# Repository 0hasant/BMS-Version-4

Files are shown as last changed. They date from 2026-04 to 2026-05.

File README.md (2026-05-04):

# Solar Team Solaris BMS Version 4

## To Do List

### Hardware Changes

1. Make the KiCad schematic more readable and understandable. Separate all ICs to their own sheets. Use hierarchical sheets. This applies to the whole project.
2. Fix the reset button issue. The RST pin is pulled low and is connected to ground through a pull-down resistor. Make the BQ76952 reset with software. // 02.05.2026 - Done by Hasan Turan.  - Hardware reset used.
3. Implement the sleep mode feature.
4. Connect the PACK pin to the positive terminal of the battery pack. //Done by Hasan Turan
5. Fix the VC0 and VC1 connections. // Done by Hasan Turan.
6. Add temperature reading to the BMS.
7. Fix the 5V regulator circuit. The cell connection can be reduced to 13 cells.
8. Revise the R32 and GND connection.// 02.05.2026 - Done by Hasan Turan.
9. Make the component naming system consistent.
10. Add an external balancing system.
11. Make the net name conventions consistent.

### Software Changes

1. Implement the voltage reading algorithm.// been doing by Hasan Turan.
2. Implement the current reading algorithm.// been doing by Hasan Turan.
3. Make a dedicated library for the BQ76952.// been doing by Hasan Turan.

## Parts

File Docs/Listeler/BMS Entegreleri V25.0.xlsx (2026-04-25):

Ürün Adı(Digi Key) | Şirket(Data Sheet) | Desteklenen Hücre Sayısı | Soc Desteği | Cloumb Counter | İnternal Regulator | Hücre Okuma Hassasiyeti | Diğer Özelikler | Fiyat | Fiyat Değişimi
MP2791DFP-0002-T (https://www.digikey.com/en/products/detail/monolithic-power-systems-inc/MP2787DFP-0000-T/22589390) | Monolithic Power Systems Inc. (https://www.monolithicpower.com/en/documentview/productdocument/index/version/2/document_type/Datasheet/lang/en/sku/MP2787DFP/document_id/9996/) | 7-16 | With MPF42790(no stock) | Error <±0.5% | 3.3V and 5V LDOs | Error <5mV (at 25°) | Hardware can be adjsut for OV-OC Protec. | $3.92 | $10.39
BQ76952PFBR (https://www.digikey.com/en/products/detail/texas-instruments/BQ76952PFBR/13427864) | Texas Instruments (https://www.ti.com/lit/ds/symlink/bq76952.pdf) | 3-16 | No | error < 1 µV (typical) | 3.3V and 5V | Error< 10 mV (typical) | Hardware can be adjsut for OV-OC Protec. | $4.66 | $9.65
TLE9012DQUXUMA1 (https://www.digikey.com/en/products/detail/infineon-technologies/TLE9012DQUXUMA1/15998980) | Infineon Technologies (https://www.infineon.com/assets/row/public/documents/10/49/infineon-tle9012dqu-datasheet-en.pdf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) | 1-12 | No | No | 3.3V | ±0.2 mV | Hardware can be adjsut for OV-OC Protec. | $7.15 | $7.16
ADES1754GCB/V+ (https://www.digikey.com/en/products/detail/analog-devices-inc-maxim-integrated/ADES1754GCB-V/22156883) | Analog Devices Inc./Maxim Integrated (https://www.analog.com/media/en/technical-documentation/data-sheets/ades1754-ades155-ades156.pdf) | 14 | No | No | 3.3V an 1.8V | Error <2.2mV | Battery-Management UART Protocol | $8.79 | $5.52
L99BM114-TR (https://www.digikey.com/en/products/detail/stmicroelectronics/L99BM114-TR/24613002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) | STMicroelectronics (https://www.st.com/resource/en/datasheet/l99bm114.pdf) | 4-14 | use cloumb and voltage | 18-bit ADC | Two 5 V regulator | Error <2mV | Battery-Management UART Protocol/Hardware can be adjsut for OV-OC Protec. | $9.15 | $5.16
MAX14920ECB+ (https://www.digikey.com/en/products/detail/analog-devices-inc-maxim-integrated/max14920ecb/3975758) | Analog Devices Inc./Maxim Integrated (https://www.analog.com/media/en/technical-documentation/data-sheets/max14920-max14921.pdf) | 1-12 | No | No | 5V LDO | ? | Aktif Kullanılan Entegre | $14.31 | $0.00

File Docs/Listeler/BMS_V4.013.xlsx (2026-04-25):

Reference | Qty | Value | Footprint | Link | Fiyat | Total Fiyat
C1,C2,C3,C4,C5,C6,C7,C8,C9,C10,C11,C12,C13,C14,C15,C16 | 16 | 200n 805 | Capacitor_SMD:C_0805_2012Metric | Link (https://www.ozdisan.com/p/smt-smd-ve-mlcc-kapasitorler-184/samsung-cl21b224kbfnnne-11149) | ₺0.45 | ₺7.23 | Yaklaşık Değer
C17 | 1 | CL31B105KCHNNNE | CL31B105KCHNNNE:CAPC3216X180N | Link (https://www.ozdisan.com/p/smt-smd-ve-mlcc-kapasitorler-184/samsung-cl31b105kchnnne-382908) | ₺1.55 | ₺1.55 | Stok Dışı
C18 | 1 | 0805 100pF +100VDC | 0805 Capacitor:CAPC2012X94N | Link (https://www.ozdisan.com/p/smt-smd-ve-mlcc-kapasitorler-184/yageo-cc0805jrnpoabn101-748443) | ₺1.17 | ₺1.17 | DigiKey
C20,C25,C26,C27,C28,C30,C32,C46 | 8 | 100nf,0805 | 0805 Capacitor:CAPC2012X94N | Link (https://www.ozdisan.com/p/smt-smd-ve-mlcc-kapasitorler-184/samsung-cl21b104kbcnnnc-14777) | ₺0.43 | ₺3.47
C21 | 1 | CL21B225KAFNNNE | 0805 Capacitor:CAPC2012X94N | Link (https://www.ozdisan.com/p/smt-smd-ve-mlcc-kapasitorler-184/samsung-cl21b225kafnnne-347149) | ₺0.96 | ₺0.96
C19,C22 | 2 | 100pf 805 | 0805 Capacitor:CAPC2012X94N | Link (https://www.ozdisan.com/p/smt-smd-ve-mlcc-kapasitorler-184/yageo-cc0805jrnpo9bn101-576598) | ₺0.39 | ₺0.77
C23 | 1 | 0.47uF | Capacitor_SMD:C_0805_2012Metric_Pad1.18x1.45mm_HandSolder | Link (https://www.ozdisan.com/p/smt-smd-ve-mlcc-kapasitorler-184/samsung-cl21b474kofnnne-10465) | ₺0.46 | ₺0.46
C24,C38 | 2 | 10uF,0805 | Capacitor_SMD:C_0805_2012Metric_Pad1.18x1.45mm_HandSolder | Link (https://www.ozdisan.com/p/smt-smd-ve-mlcc-kapasitorler-184/samsung-cl21a106kpfnnne-336384) | ₺0.44 | ₺0.88
C29,C31,C47,C48 | 4 | 22pf,0805 | 0805 Capacitor:CAPC2012X94N | Link (https://www.ozdisan.com/p/smt-smd-ve-mlcc-kapasitorler-184/samsung-cl21c220jbannnc-5638) | ₺0.38 | ₺1.51
C33 | 1 | 3.3nF | Capacitor_THT:C_Disc_D10.5mm_W5.0mm_P5.00mm | Link (https://www.ozdisan.com/p/smt-smd-ve-mlcc-kapasitorler-184/yageo-cc0805krx7r9bb332-587305) | ₺0.47 | ₺0.47
C34,C35 | 2 | 30pF | Capacitor_SMD:C_0805_2012Metric_Pad1.18x1.45mm_HandSolder | Link (https://www.ozdisan.com/p/smt-smd-ve-mlcc-kapasitorler-184/yageo-cc0805jrnpo9bn330-748296) | ₺0.51 | ₺1.01
C36 | 1 | 10pF | Capacitor_SMD:C_0805_2012Metric_Pad1.18x1.45mm_HandSolder | Link (https://www.ozdisan.com/p/smt-smd-ve-mlcc-kapasitorler-184/yageo-cc0805grnpo9bn100-529510) | ₺1.02 | ₺1.02
C37 | 1 | 4.7uF,0805 | 0805 Capacitor:CAPC2012X94N | Link (https://www.ozdisan.com/p/smt-smd-ve-mlcc-kapasitorler-184/samsung-cl21a475kaqnnne-441542) | ₺0.77 | ₺0.77
C43,C44 | 2 | 0805 1u | 0805 Capacitor:CAPC2012X94N | Link (https://www.ozdisan.com/p/smt-smd-ve-mlcc-kapasitorler-184/samsung-cl21b105kofnnne-29632) | ₺0.33 | ₺0.67
C45 | 1 | 805 10n | 0805 Capacitor:CAPC2012X94N | Link (https://www.ozdisan.com/p/smt-smd-ve-mlcc-kapasitorler-184/yageo-cc0805kpx7r9bb103-524578) | ₺0.29 | ₺0.29
C49 | 1 | 4.7uF,1210,100V | Capacitor_SMD:C_1210_3225Metric | Link |  | ₺0.00
D1 | 1 | BAT46W-7-F | BAT46W-7-F:SOD3715X145N | Link (https://www.ozdisan.com/p/schottky-diyotlar-385/diodes-bat46w-7-f-982659) | ₺2.49 | ₺2.49
D5 | 1 | DFLS2100-7 | SamacSys_Parts:DFLS21007 | Link (https://www.ozdisan.com/p/schottky-diyotlar-385/diodes-dfls2100-7-627311) | ₺13.67 | ₺13.67
IC2 | 1 | TPS73233DBVR | SOT95P280X145-5N | Link (https://www.ozdisan.com/p/lineer-voltaj-regulatorleri-279/texas-tps73233dbvr-588532) | ₺37.84 | ₺37.84
IC3 | 1 | RAA2118054GP3#JA0 | SamacSys_Parts:SOT95P280X110-5N | Link (https://www.digikey.com/en/products/detail/renesas-electronics-corporation/RAA2118054GP3-JA0/22162357) |  | ₺0.00
J1,J2,J3 | 3 | 15EDGRC-3.81-06P-14-00A_H_ | SamacSys_Parts:SHDRRA6W80P0X381_1X6_2365X920X754P | Link (https://www.ozdisan.com/p/gecmeli-klemensler-411/golten-15egtrc-3-81-06p-13-00ah-741341) | ₺5.95 | ₺17.86
J4 | 1 | DS1013-10SSIB1 | Connector_IDC:IDC-Header_2x05_P2.54mm_Vertical | Link (https://www.ozdisan.com/p/box-headerlar-295/kls-electronic-l-kls1-202-10-r-b-457444) | ₺2.65 | ₺2.65
J5 | 1 | Screw_Terminal_01x04 | TerminalBlock_Phoenix:TerminalBlock_Phoenix_MKDS-1,5-4-5.08_1x04_P5.08mm_Horizontal | Link (https://www.ozdisan.com/p/pcb-klemensler-410/degson-dg142r-5-08-04p-14-00ah-700305) | ₺13.69 | ₺13.69
J6,J7,J10,J11 | 4 | 380-10-103-00-002000 | HDRV3W51P0X254_1X3_762X254X470P | Link (https://www.ozdisan.com/p/pin-headerlar-293/connfly-ds1021-1x3sf11-b-445706) | ₺0.64 | ₺2.58
J8,J9 | 2 | K51-00A_H_ | K5100AH | Link |  | ₺0.00
L2 | 1 | NRS4018T220MDGJ | SamacSys_Parts:NRS4018T220MDGJ | Link (https://www.ozdisan.com/p/sabit-induktorler-468/taiyo-yuden-nrs4018t220mdgj-732699) | ₺5.73 | ₺5.73
LED1 | 1 | KP-2012SRC-PRV | SamacSys_Parts:LEDC2012X110N | Link (https://www.ozdisan.com/p/sinyal-ledler-tek-renkli-361/kingbright-kp-2012src-prv-634977) | ₺3.08 | ₺3.08
PS2 | 1 | 1S4E_1505S1U | 1S4E_0303S1U | Link (https://www.digikey.com/en/products/detail/gaptec-electronic/1S4E-1505S1U/13692452) | ₺116.06 | ₺116.06
R1,R2,R3,R4,R5,R6,R7,R8,R9,R10,R11,R12,R13,R14,R15,R16,R17 | 17 | 0805 20 Ohms 1% | SamacSys_Parts:RESC2012X70N | Link (https://www.ozdisan.com/p/smt-smd-ve-cip-direncler-194/royalohm-0805s8f200jt5e-453058) | ₺0.06 | ₺1.03
R18,R19,R20,R24,R36 | 5 | 0805 100 Ohms 1% | 0805 Resistor:RES_ERA6AHD330V | Link (https://www.ozdisan.com/p/smt-smd-ve-cip-direncler-194/royalohm-0805s8f1000t5e-30250) | ₺0.06 | ₺0.30
R21 | 1 | BVS-A-R002-1.0 | PSR400ITQFJ2L00:RESC10052X125N | Link (https://www.ozdisan.com/p/hassas-ve-sont-direncler-195/isabellenhutte-bvs-a-r002-1-0-536227) | ₺52.09 | ₺52.09
R22,R23,R25 | 3 | 10k 0805 | 0805 Resistor:RES_ERA6AHD330V | Link (https://www.ozdisan.com/p/smt-smd-ve-cip-direncler-194/viking-crt05f7e1002-1054384) | ₺0.06 | ₺0.17
R26 | 1 | 330R | Resistor_SMD:R_0805_2012Metric_Pad1.20x1.40mm_HandSolder | Link (https://www.ozdisan.com/p/smt-smd-ve-cip-direncler-194/viking-crt05f7e3300-1054389) | ₺0.06 | ₺0.06
R27,R28 | 2 | 0805,1M,1% | 0805 Resistor:RES_ERA6AHD330V | Link (https://www.ozdisan.com/p/smt-smd-ve-cip-direncler-194/royalohm-0805s8f1004t5e-29700) | ₺0.09 | ₺0.18
R29 | 1 | 200R,0805 | LED_SMD:LED_0805_2012Metric_Pad1.15x1.40mm_HandSolder | Link (https://www.ozdisan.com/p/smt-smd-ve-cip-direncler-194/royalohm-0805s8f2000t5e-404862) | ₺0.06 | ₺0.06
R30,R37 | 2 | 60R | Resistor_SMD:R_0805_2012Metric_Pad1.20x1.40mm_HandSolder | Link (https://www.ozdisan.com/p/smt-smd-ve-cip-direncler-194/royalohm-0805s8f604jt5e-505356) | ₺0.06 | ₺0.12
R31 | 1 | 1k 805 | SamacSys_Parts:RESC2012X70N | Link (https://www.ozdisan.com/p/smt-smd-ve-cip-direncler-194/yageo-rc0805fr-071kl-460155) | ₺0.11 | ₺0.11
R32 | 1 | 0R | SamacSys_Parts:RESC2012X70N | Link (https://www.ozdisan.com/p/smt-smd-ve-cip-direncler-194/royalohm-0805s8f0000t5e-339579) | ₺0.06 | ₺0.06
R35 | 1 | 4.7k | Resistor_SMD:R_0805_2012Metric_Pad1.20x1.40mm_HandSolder | Link (https://www.ozdisan.com/p/smt-smd-ve-cip-direncler-194/royalohm-cq05s8f4701t5e-588006) | ₺0.08 | ₺0.08
S1,S2 | 2 | DTS-62R-V | SamacSys_Parts:DTS62RV | Link (https://www.ozdisan.com/p/tact-sivicler-485/diptronics-dts-62r-v-476750) | ₺3.15 | ₺6.29
U1 | 1 | BQ76952PFBR | BQ76952PFBR:QFP50P900X900X120-48N | Link (https://www.ozdisan.com/p/batarya-yonetimi-entegreleri-272/texas-bq76952pfbr-993252) | ₺200.59 | ₺200.59
U2 | 1 | REF3033 | Package_TO_SOT_SMD:SOT-23 | Link (https://www.ozdisan.com/p/voltaj-referans-entegreleri-287/texas-ref3033aidbzr-616752) | ₺36.38 | ₺36.38
U3 | 1 | STM32F103C8Tx | Package_QFP:LQFP-48_7x7mm_P0.5mm | Link (https://www.ozdisan.com/p/mikroislemciler-218/stm-stm32f103c8t6-368374) | ₺51.09 | ₺51.09
U4 | 1 | ISO1050DUB | Package_SO:SOP-8_6.62x9.15mm_P2.54mm | Link (https://www.ozdisan.com/p/driver-receiver-ve-transceiver-entegreleri-229/texas-iso1050dubr-348272) | ₺53.49 | ₺53.49
Y1 | 1 | RH100-16.000-18-3050-TR | RH10016000183050TR | Link (https://www.ozdisan.com/p/kristaller-508/raltron-rh100-27-000-18-f-2020-488864) | ₺12.20 | ₺12.20
Total |  |  |  |  |  | ₺652.19
Total

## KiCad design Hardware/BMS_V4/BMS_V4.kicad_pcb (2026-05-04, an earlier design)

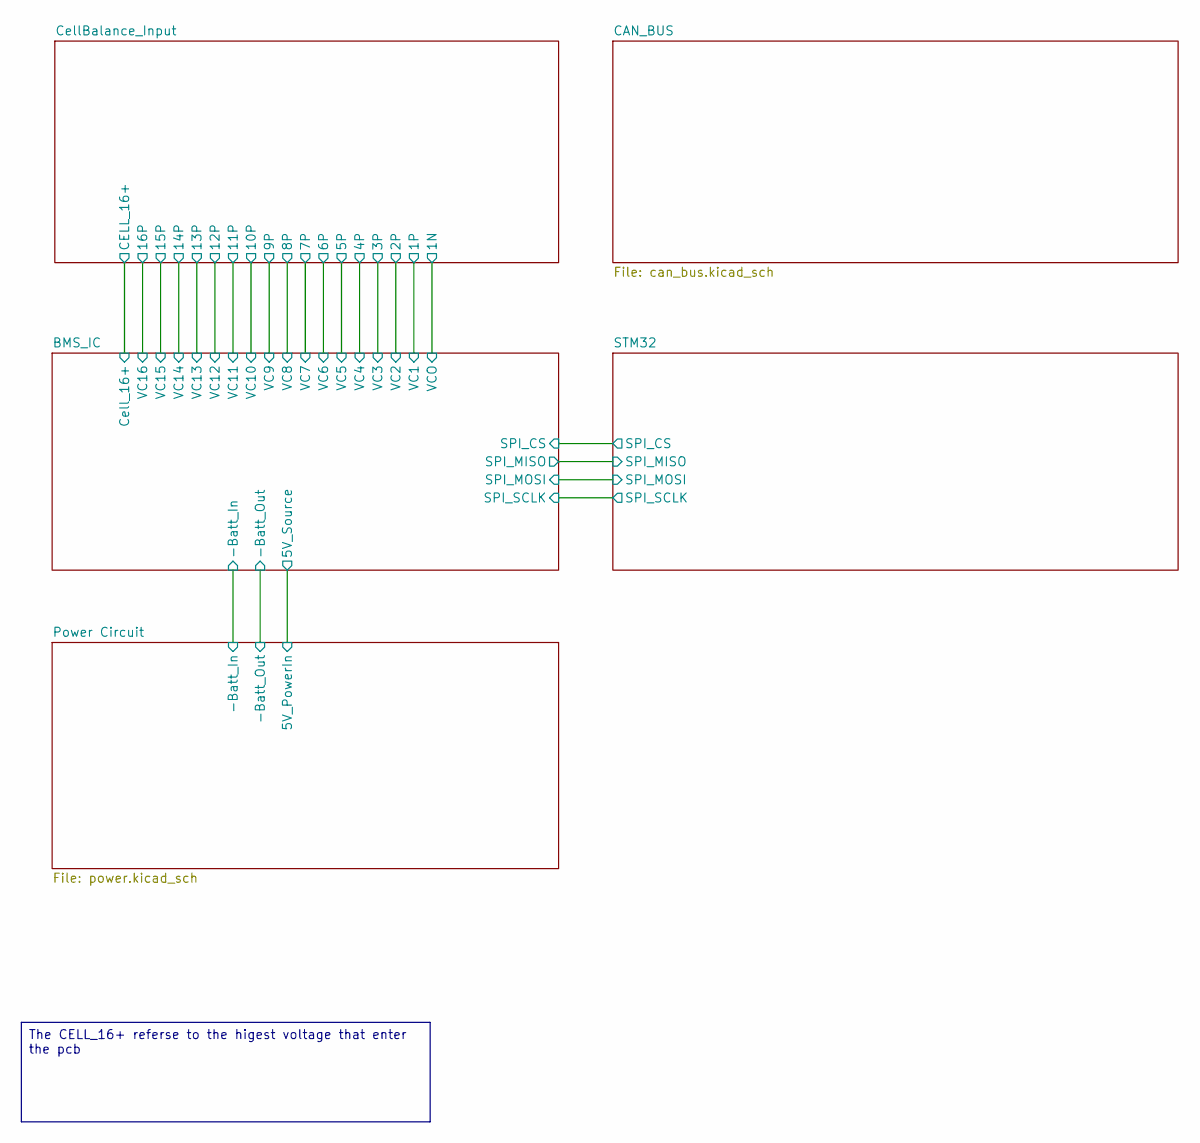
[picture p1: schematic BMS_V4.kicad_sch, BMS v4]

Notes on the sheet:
The CELL_16+ referse to the higest voltage that enter the pcb

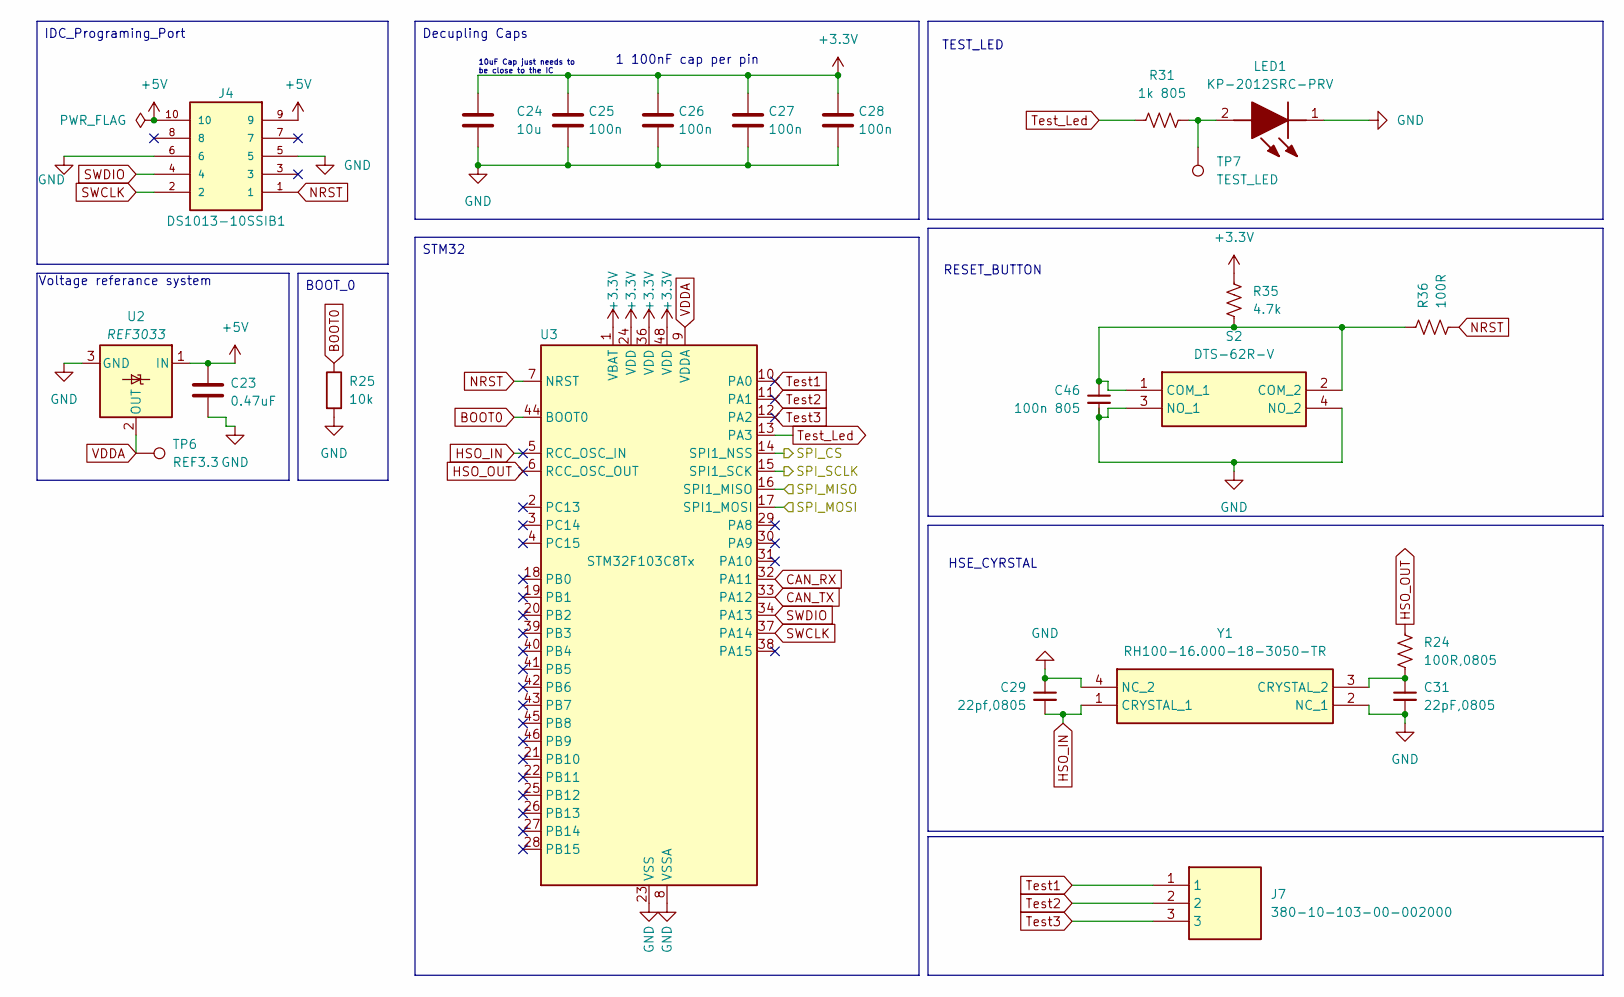
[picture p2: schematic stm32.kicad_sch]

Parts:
C23: 0.47uF; C_0805_2012Metric_Pad1.18x1.45mm_HandSolder
C24: 10u; C_0805_2012Metric_Pad1.18x1.45mm_HandSolder
C25, C26, C27, C28: 100n; C_0805_2012Metric_Pad1.18x1.45mm_HandSolder
C29: 22pf,0805; CAPC2012X94N
C31: 22pF,0805; CAPC2012X94N
C46: 100n 805; C_0805_2012Metric_Pad1.18x1.45mm_HandSolder
J4: DS1013-10SSIB1; IDC-Header_2x05_P2.54mm_Vertical; PARTREV G
J7: 380-10-103-00-002000; HDRV3W51P0X254_1X3_762X254X470P; Manufacturer_Part_Number 380-10-103-00-002000; Mouser Part Number 575-3801010300002000
LED1: KP-2012SRC-PRV; LEDC2012X110N; Manufacturer_Part_Number KP-2012SRC-PRV; Mouser Part Number N/A
R24: 100R,0805; RES_ERA6AHD330V
R25: 10k; R_0805_2012Metric_Pad1.20x1.40mm_HandSolder
R31: 1k 805; RESC2012X70N
R35: 4.7k; R_0805_2012Metric_Pad1.20x1.40mm_HandSolder
R36: 100R; R_0805_2012Metric_Pad1.20x1.40mm_HandSolder
S2: DTS-62R-V; DTS62RV; Manufacturer_Part_Number DTS-62R-V; Mouser Part Number 113-DTS62RV
TP6: REF3.3; TestPoint_THTPad_D1.0mm_Drill0.5mm
TP7: TEST_LED; TestPoint_THTPad_D1.0mm_Drill0.5mm
U2: REF3033; SOT-23
U3: STM32F103C8Tx; LQFP-48_7x7mm_P0.5mm
Y1: RH100-16.000-18-3050-TR; RH10016000183050TR; Manufacturer_Part_Number RH100-16.000-18-3050-TR

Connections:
+3.3V: C24.1, C25.1, C26.1, C27.1, C28.1, R35.2, U3.1 (VBAT), U3.24 (VDD), U3.36 (VDD), U3.48 (VDD); also elsewhere on the board
+5V: C23.1, J4.9, J4.10, U2.1 (IN); also elsewhere on the board
/BMS_IC/SPI_CS: U3.14 (SPI1_NSS); also elsewhere on the board
/BMS_IC/SPI_MISO: U3.16 (SPI1_MISO); also elsewhere on the board
/BMS_IC/SPI_MOSI: U3.17 (SPI1_MOSI); also elsewhere on the board
/BMS_IC/SPI_SCLK: U3.15 (SPI1_SCK); also elsewhere on the board
BOOT0: R25.1, U3.44 (BOOT0)
CAN_RX: U3.32 (PA11); also elsewhere on the board
CAN_TX: U3.33 (PA12); also elsewhere on the board
GND: C23.2, C24.2, C25.2, C26.2, C27.2, C28.2, C29.1, C31.2, C46.2, J4.5, J4.6, LED1.1 (K), R25.2, S2.3 (NO_1), S2.4 (NO_2), U2.3 (GND), U3.8 (VSSA), U3.23 (VSS), U3.35 (VSS), U3.47 (VSS), Y1.2 (NC_1), Y1.4 (NC_2); also elsewhere on the board
HSO_IN: C29.2, U3.5 (RCC_OSC_IN), Y1.1 (CRYSTAL_1)
HSO_OUT: R24.1, U3.6 (RCC_OSC_OUT)
NRST: J4.1, R36.1, U3.7 (NRST)
unnamed: LED1.2 (A), R31.2, TP7.1
unnamed: C46.1, R35.1, R36.2, S2.1 (COM_1), S2.2 (COM_2)
unnamed: C31.1, R24.2, Y1.3 (CRYSTAL_2)
SWCLK: J4.2, U3.37 (PA14)
SWDIO: J4.4, U3.34 (PA13)
Test1: J7.1, U3.10 (PA0)
Test2: J7.2, U3.11 (PA1)
Test3: J7.3, U3.12 (PA2)
Test_Led: R31.1, U3.13 (PA3)
VDDA: TP6.1, U2.2 (OUT), U3.9 (VDDA)

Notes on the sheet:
HSE_CYRSTAL
TEST_LED
1 100nF cap per pin
Voltage referance system
RESET_BUTTON
10uF Cap just needs to be close to the IC
BOOT_0
IDC_Programing_Port
Decupling Caps
STM32

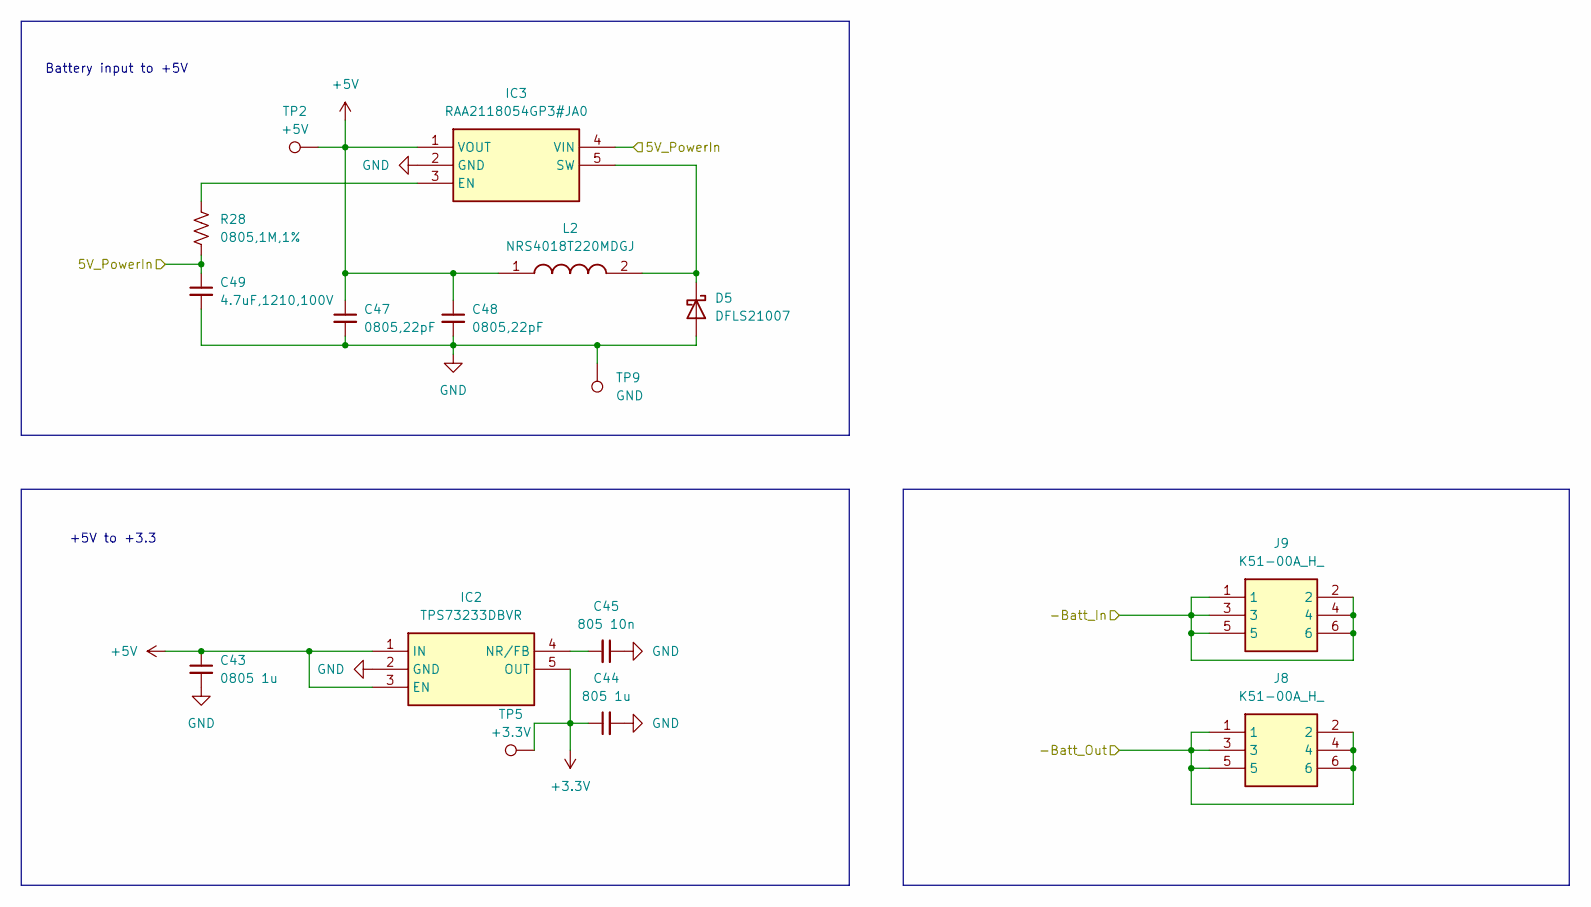
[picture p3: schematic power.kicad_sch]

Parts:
C43: 0805 1u; CAPC2012X94N
C44: 805 1u; CAPC2012X94N
C45: 805 10n; CAPC2012X94N
C47, C48: 0805,22pF; CAPC2012X94N
C49: 4.7uF,1210,100V; C_1210_3225Metric
D5: DFLS21007
IC2: TPS73233DBVR; SOT95P280X145-5N; Manufacturer_Part_Number TPS73233DBVR; Mouser Part Number 595-TPS73233DBVR
IC3: RAA2118054GP3#JA0; SOT95P280X110-5N; Manufacturer_Part_Number RAA2118054GP3#JA0; Mouser Part Number 968-RAA2118054GP3JA0
J8, J9: K51-00A_H_; K5100AH; Manufacturer_Part_Number K51-00A(H)
L2: NRS4018T220MDGJ; Manufacturer_Part_Number NRS4018T220MDGJ; Mouser Part Number 963-NRS4018T220MDGJ
R28: 0805,1M,1%; RES_ERA6AHD330V
TP2: +5V; TestPoint_THTPad_D1.0mm_Drill0.5mm
TP5: +3.3V; TestPoint_THTPad_D1.0mm_Drill0.5mm
TP9: GND; TestPoint_2Pads_Pitch5.08mm_Drill1.3mm

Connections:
+3.3V: C44.1, IC2.5 (OUT), TP5.1; also elsewhere on the board
+5V: C43.1, C47.1, C48.1, IC2.1 (IN), IC2.3 (EN), IC3.1 (VOUT), L2.1, TP2.1; also elsewhere on the board
/BMS_IC/-Batt_In: J9.1, J9.2, J9.3, J9.4, J9.5, J9.6; also elsewhere on the board
/BMS_IC/-Batt_Out: J8.1, J8.2, J8.3, J8.4, J8.5, J8.6; also elsewhere on the board
GND: C43.2, C44.2, C45.1, C47.2, C48.2, C49.2, D5.2 (A), IC2.2 (GND), IC3.2 (GND), TP9.1; also elsewhere on the board
unnamed: D5.1 (K), IC3.5 (SW), L2.2
unnamed: C45.2, IC2.4 (NR/FB)
unnamed: IC3.3 (EN), R28.1

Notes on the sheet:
+5V to +3.3
Battery input to +5V

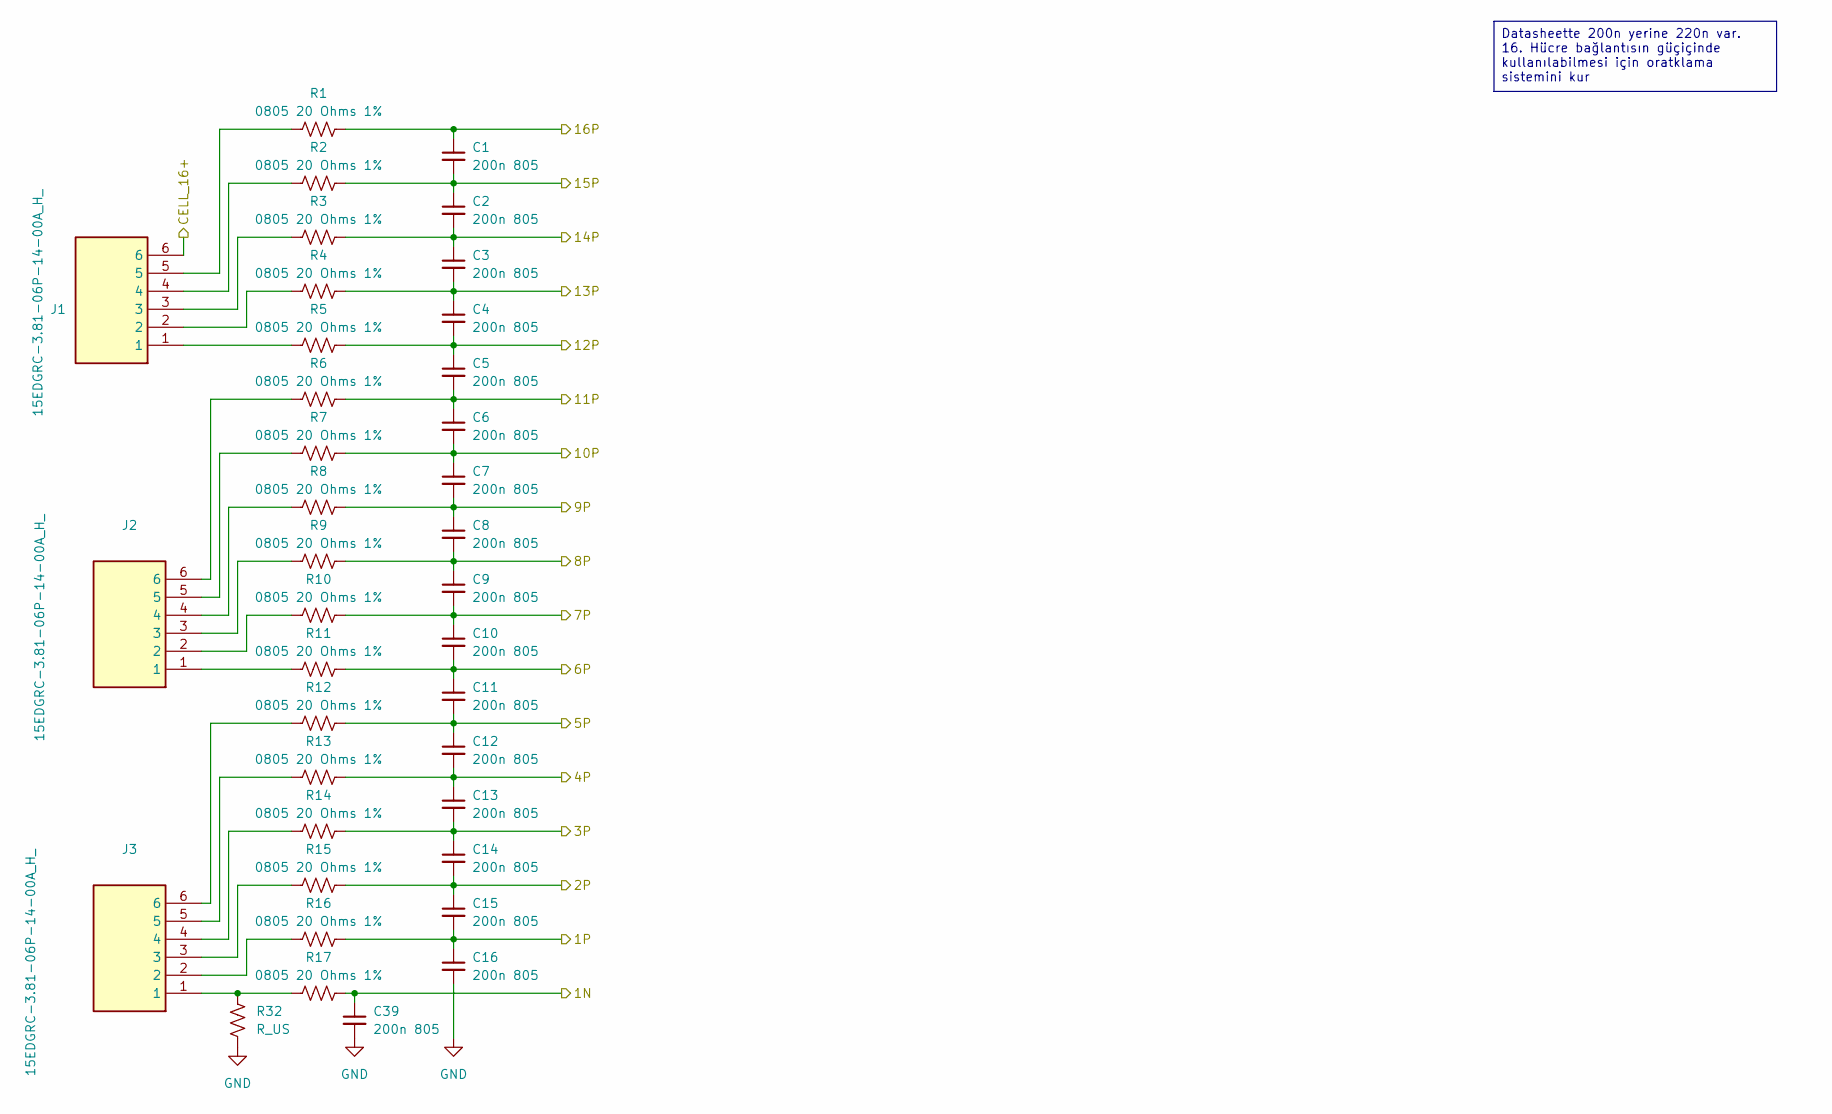
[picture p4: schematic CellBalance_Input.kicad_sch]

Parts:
C1, C2, C3, C4, C5, C6, C7, C8, C9, C10, C11, C12, C13, C14, C15, C16, C39: 200n 805; C_0805_2012Metric
J1, J2, J3: 15EDGRC-3.81-06P-14-00A_H_; SHDRRA6W80P0X381_1X6_2365X920X754P; Manufacturer_Part_Number 15EDGRC-3.81-06P-14-00A(H)
R1, R2, R3, R4, R5, R6, R7, R8, R9, R10, R11, R12, R13, R14, R15, R16, R17: 0805 20 Ohms 1%; RESC2012X70N
R32: R_US; R_0805_2012Metric_Pad1.20x1.40mm_HandSolder

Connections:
/BMS_IC/Cell_16+: J1.6; also elsewhere on the board
/BMS_IC/VC1: C15.2, C16.1, R16.2; also elsewhere on the board
/BMS_IC/VC2: C14.2, C15.1, R15.2; also elsewhere on the board
/BMS_IC/VC3: C13.2, C14.1, R14.2; also elsewhere on the board
/BMS_IC/VC4: C12.2, C13.1, R13.2; also elsewhere on the board
/BMS_IC/VC5: C11.2, C12.1, R12.2; also elsewhere on the board
/BMS_IC/VC6: C10.2, C11.1, R11.2; also elsewhere on the board
/BMS_IC/VC7: C9.2, C10.1, R10.2; also elsewhere on the board
/BMS_IC/VC8: C8.2, C9.1, R9.2; also elsewhere on the board
/BMS_IC/VC9: C7.2, C8.1, R8.2; also elsewhere on the board
/BMS_IC/VC10: C6.2, C7.1, R7.2; also elsewhere on the board
/BMS_IC/VC11: C5.2, C6.1, R6.2; also elsewhere on the board
/BMS_IC/VC12: C4.2, C5.1, R5.2; also elsewhere on the board
/BMS_IC/VC13: C3.2, C4.1, R4.2; also elsewhere on the board
/BMS_IC/VC14: C2.2, C3.1, R3.2; also elsewhere on the board
/BMS_IC/VC15: C1.2, C2.1, R2.2; also elsewhere on the board
/BMS_IC/VC16: C1.1, R1.2; also elsewhere on the board
/BMS_IC/VCO: C39.1, R17.2; also elsewhere on the board
GND: C16.2, C39.2, R32.2; also elsewhere on the board
unnamed: J1.1, R5.1
unnamed: J1.2, R4.1
unnamed: J1.3, R3.1
unnamed: J1.4, R2.1
unnamed: J1.5, R1.1
unnamed: J2.1, R11.1
unnamed: J2.2, R10.1
unnamed: J2.3, R9.1
unnamed: J2.4, R8.1
unnamed: J2.5, R7.1
unnamed: J2.6, R6.1
unnamed: J3.1, R17.1, R32.1
unnamed: J3.2, R16.1
unnamed: J3.3, R15.1
unnamed: J3.4, R14.1
unnamed: J3.5, R13.1
unnamed: J3.6, R12.1

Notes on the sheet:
Datasheette 200n yerine 220n var. 16. Hücre bağlantısın güçiçinde kullanılabilmesi için oratklama sistemini kur

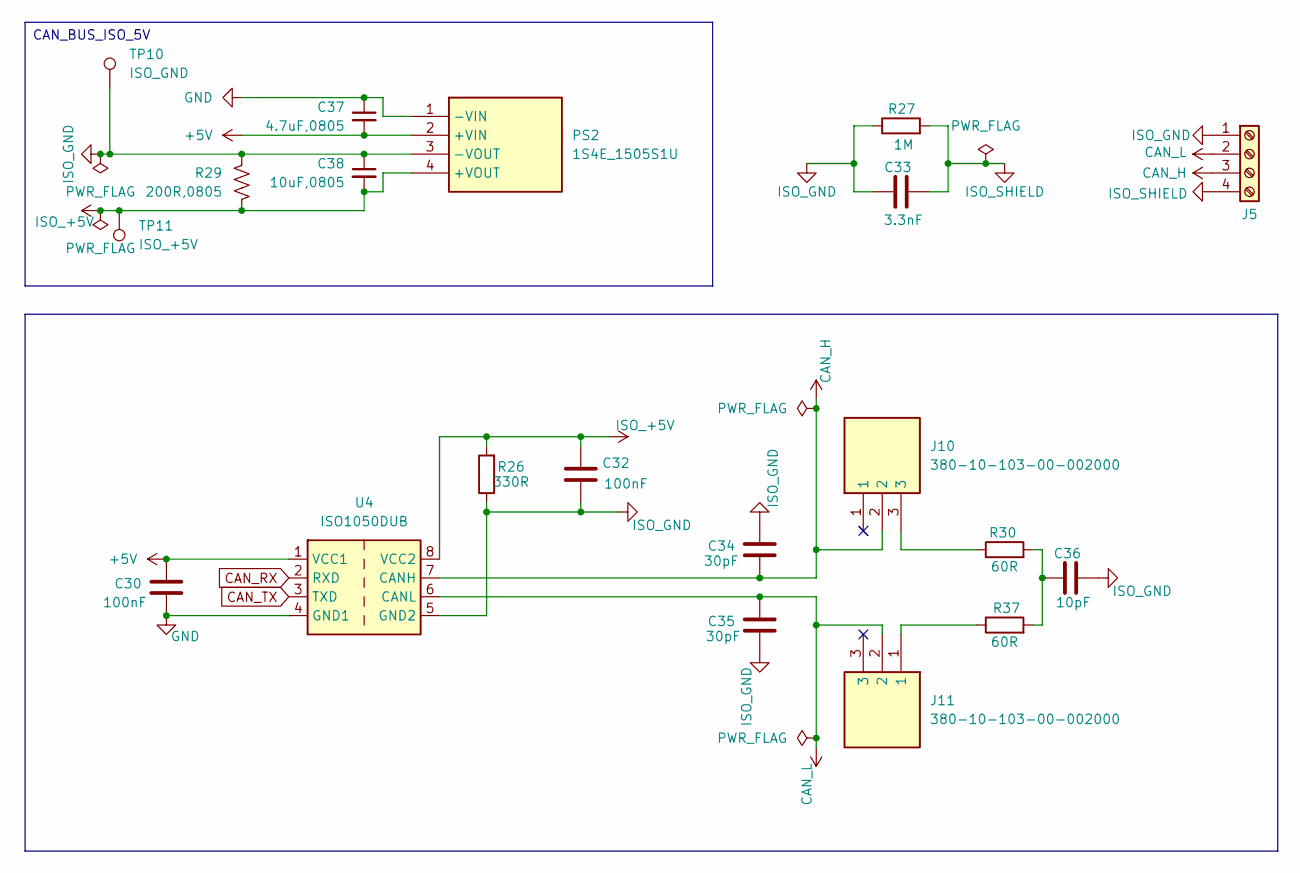
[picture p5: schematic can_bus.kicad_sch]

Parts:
C30, C32: 100nF; C_0805_2012Metric_Pad1.18x1.45mm_HandSolder
C33: 3.3nF; C_Disc_D10.5mm_W5.0mm_P5.00mm
C34, C35: 30pF; C_0805_2012Metric_Pad1.18x1.45mm_HandSolder
C36: 10pF; C_0805_2012Metric_Pad1.18x1.45mm_HandSolder
C37: 4.7uF,0805; CAPC2012X94N
C38: 10uF,0805; CAPC2012X94N
J5: Screw_Terminal_01x04; TerminalBlock_Phoenix_MKDS-1,5-4-5.08_1x04_P5.08mm_Horizont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
J10, J11: 380-10-103-00-002000; HDRV3W51P0X254_1X3_762X254X470P; Manufacturer_Part_Number 380-10-103-00-002000; Mouser Part Number 575-3801010300002000
PS2: 1S4E_1505S1U; 1S4E_0303S1U; Manufacturer_Part_Number 1S4E_1505S1U
R26: 330R; R_0805_2012Metric_Pad1.20x1.40mm_HandSolder
R27: 1M; R_0805_2012Metric_Pad1.20x1.40mm_HandSolder
R29: 200R,0805; LED_0805_2012Metric_Pad1.15x1.40mm_HandSolder
R30, R37: 60R; R_0805_2012Metric_Pad1.20x1.40mm_HandSolder
TP10: ISO_GND; TestPoint_THTPad_D1.0mm_Drill0.5mm
TP11: ISO_+5V; TestPoint_THTPad_D1.0mm_Drill0.5mm
U4: ISO1050DUB; SOP-8_6.62x9.15mm_P2.54mm

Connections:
+5V: C30.1, C37.2, PS2.2 (+VIN), U4.1 (VCC1); also elsewhere on the board
CAN_H: C34.2, J5.3, J10.2, U4.7 (CANH)
CAN_L: C35.1, J5.2, J11.2, U4.6 (CANL)
CAN_RX: U4.2 (RXD); also elsewhere on the board
CAN_TX: U4.3 (TXD); also elsewhere on the board
GND: C30.2, C37.1, PS2.1 (-VIN), U4.4 (GND1); also elsewhere on the board
ISO_+5V: C32.1, C38.2, PS2.4 (+VOUT), R26.2, R29.2, TP11.1, U4.8 (VCC2)
ISO_GND: C32.2, C33.1, C34.1, C35.2, C36.2, C38.1, J5.1, PS2.3 (-VOUT), R26.1, R27.1, R29.1, TP10.1, U4.5 (GND2)
ISO_SHIELD: C33.2, J5.4, R27.2
unnamed: C36.1, R30.2, R37.2
unnamed: J10.3, R30.1
unnamed: J11.1, R37.1

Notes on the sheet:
CAN_BUS_ISO_5V

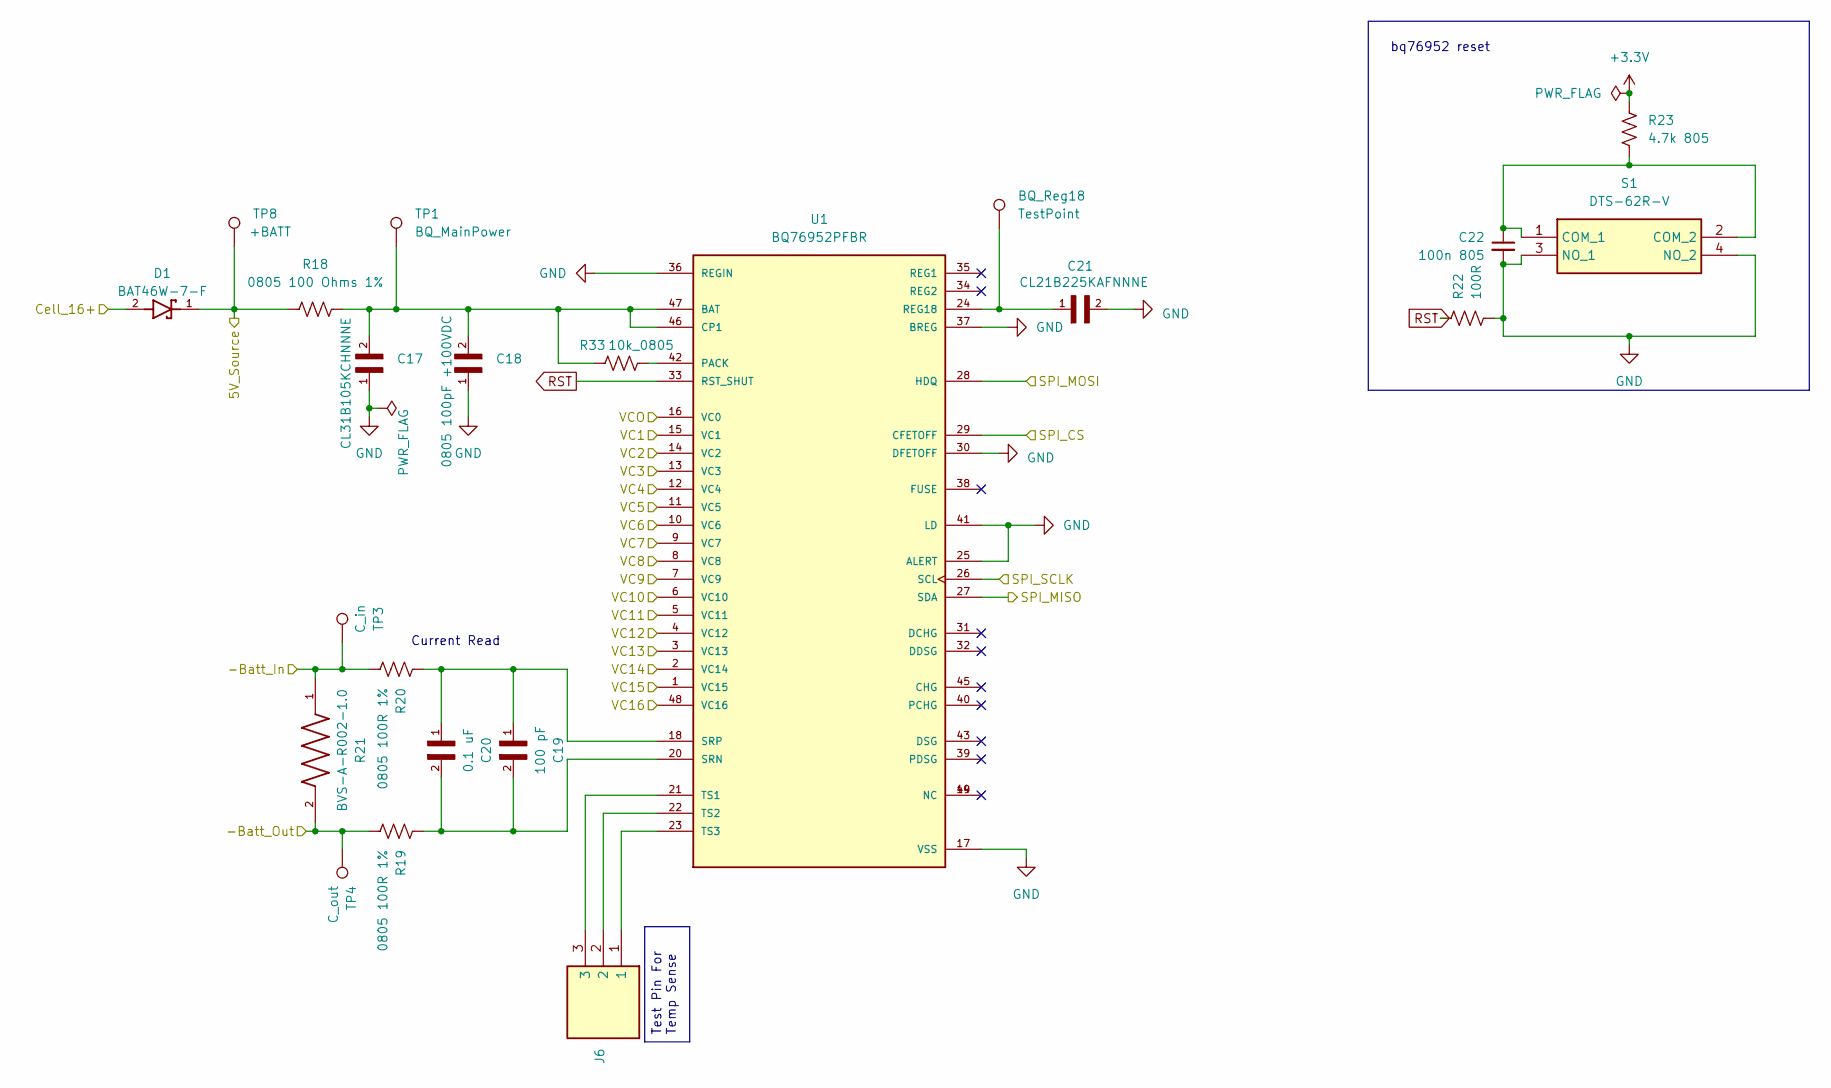
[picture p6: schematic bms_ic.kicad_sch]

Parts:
BQ_Reg18: TestPoint; Pin_D0.7mm_L6.5mm_W1.8mm_FlatFork
C17: CL31B105KCHNNNE; C_1206_3216Metric_Pad1.33x1.80mm_HandSolder
C18: 0805 100pF +100VDC; CAPC2012X94N
C19: 100 pF; CAPC2012X94N
C20: 0.1 uF; CAPC2012X94N
C21: CL21B225KAFNNNE; CAPC2012X94N
C22: 100n 805; C_0805_2012Metric_Pad1.18x1.45mm_HandSolder
D1: BAT46W-7-F; SOD3715X145N; PARTREV 18 - 2
J6: 380-10-103-00-002000; HDRV3W51P0X254_1X3_762X254X470P; Manufacturer_Part_Number 380-10-103-00-002000; Mouser Part Number 575-3801010300002000
R18: 0805 100 Ohms 1%; R_0805_2012Metric_Pad1.20x1.40mm_HandSolder
R19, R20: 0805 100R 1%; RES_ERA6AHD330V
R21: BVS-A-R002-1.0; RESC10052X125N
R22: 100R; R_0805_2012Metric_Pad1.20x1.40mm_HandSolder
R23: 4.7k 805; R_0805_2012Metric_Pad1.20x1.40mm_HandSolder
R33: 10k_0805; R_0805_2012Metric_Pad1.20x1.40mm_HandSolder
S1: DTS-62R-V; DTS62RV; Manufacturer_Part_Number DTS-62R-V; Mouser Part Number 113-DTS62RV
TP1: BQ_MainPower; TestPoint_THTPad_D1.0mm_Drill0.5mm
TP3: C_in; TestPoint_THTPad_D1.0mm_Drill0.5mm
TP4: C_out; TestPoint_THTPad_D1.0mm_Drill0.5mm
TP8: +BATT; TestPoint_THTPad_D1.0mm_Drill0.5mm
U1: BQ76952PFBR; QFP50P900X900X120-48N; PARTREV B

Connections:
+3.3V: R23.1; also elsewhere on the board
/BMS_IC/-Batt_In: R20.2, R21.1, TP3.1; also elsewhere on the board
/BMS_IC/-Batt_Out: R19.2, R21.2, TP4.1; also elsewhere on the board
/BMS_IC/Cell_16+: D1.2; also elsewhere on the board
/BMS_IC/SPI_CS: U1.29 (CFETOFF); also elsewhere on the board
/BMS_IC/SPI_MISO: U1.27 (SDA); also elsewhere on the board
/BMS_IC/SPI_MOSI: U1.28 (HDQ); also elsewhere on the board
/BMS_IC/SPI_SCLK: U1.26 (SCL); also elsewhere on the board
/BMS_IC/VC1: U1.15 (VC1); also elsewhere on the board
/BMS_IC/VC2: U1.14 (VC2); also elsewhere on the board
/BMS_IC/VC3: U1.13 (VC3); also elsewhere on the board
/BMS_IC/VC4: U1.12 (VC4); also elsewhere on the board
/BMS_IC/VC5: U1.11 (VC5); also elsewhere on the board
/BMS_IC/VC6: U1.10 (VC6); also elsewhere on the board
/BMS_IC/VC7: U1.9 (VC7); also elsewhere on the board
/BMS_IC/VC8: U1.8 (VC8); also elsewhere on the board
/BMS_IC/VC9: U1.7 (VC9); also elsewhere on the board
/BMS_IC/VC10: U1.6 (VC10); also elsewhere on the board
/BMS_IC/VC11: U1.5 (VC11); also elsewhere on the board
/BMS_IC/VC12: U1.4 (VC12); also elsewhere on the board
/BMS_IC/VC13: U1.3 (VC13); also elsewhere on the board
/BMS_IC/VC14: U1.2 (VC14); also elsewhere on the board
/BMS_IC/VC15: U1.1 (VC15); also elsewhere on the board
/BMS_IC/VC16: U1.48 (VC16); also elsewhere on the board
/BMS_IC/VCO: U1.16 (VC0); also elsewhere on the board
GND: C17.1, C18.1, C21.2, C22.2, R22.1, S1.3 (NO_1), S1.4 (NO_2), U1.17 (VSS), U1.25 (ALERT), U1.30 (DFETOFF), U1.36 (REGIN), U1.37 (BREG), U1.41 (LD); also elsewhere on the board
unnamed: C22.1, R23.2, S1.1 (COM_1), S1.2 (COM_2)
unnamed: C17.2, C18.2, R18.2, R33.1, TP1.1, U1.46 (CP1), U1.47 (BAT)
unnamed: R33.2, U1.42 (PACK)
unnamed: BQ_Reg18.1, C21.1, U1.24 (REG18)
unnamed: C19.2, C20.2, R19.1, U1.20 (SRN)
unnamed: C19.1, C20.1, R20.1, U1.18 (SRP)
unnamed: J6.3, U1.21 (TS1)
unnamed: J6.2, U1.22 (TS2)
unnamed: J6.1, U1.23 (TS3)
RST: R22.2, U1.33 (RST_SHUT)

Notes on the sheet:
Current Read
bq76952 reset
Test Pin For Temp Sense

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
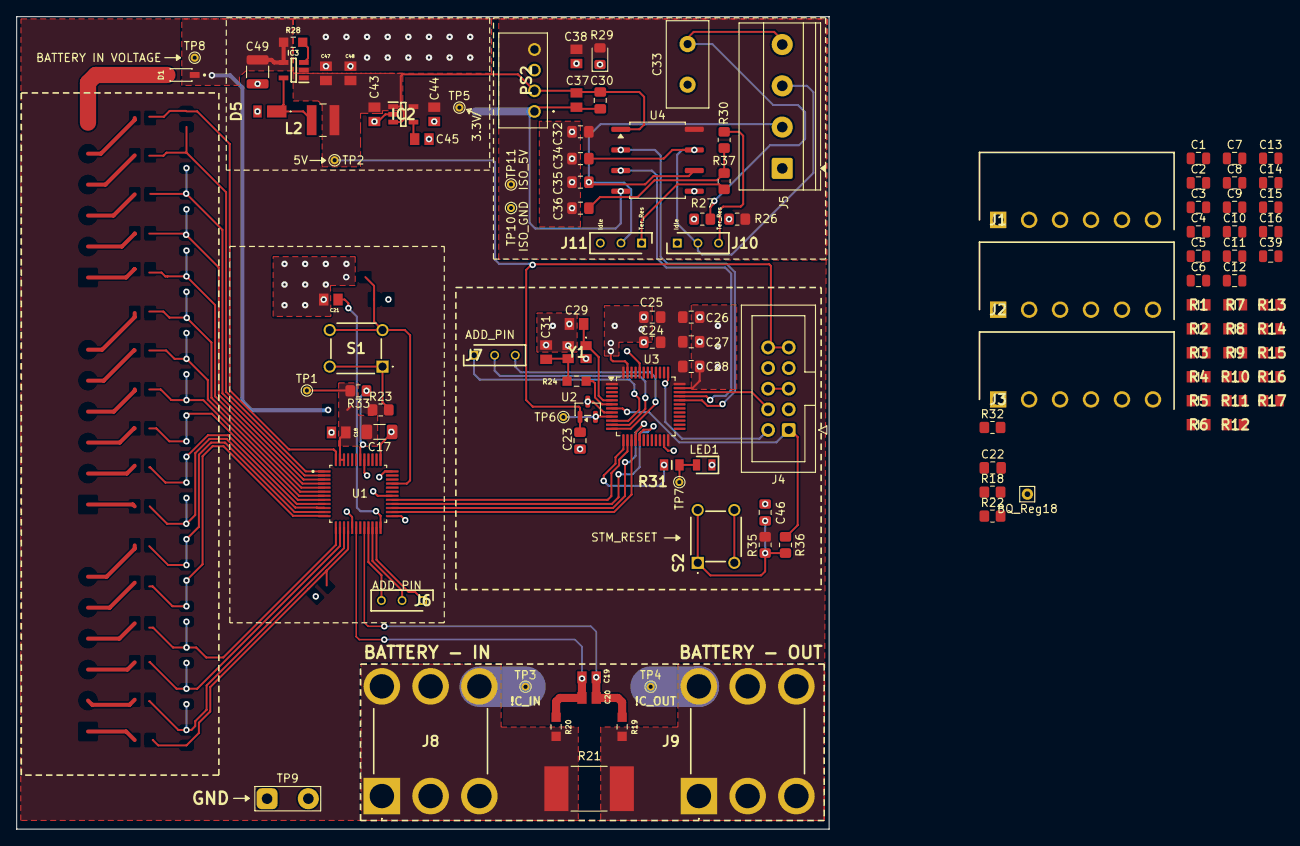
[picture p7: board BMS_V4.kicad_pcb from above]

Board: 2 copper layers, 100.0 x 100.0 mm, 119 parts (1 on the bottom side), 82 nets.

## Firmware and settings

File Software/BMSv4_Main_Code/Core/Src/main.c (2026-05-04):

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
/* Includes ------------------------------------------------------------------*/
#include "main.h"
#include "bq76952.h"
//V1.0.1 -Hasan Turan

SPI_HandleTypeDef hspi1;

/* USER CODE BEGIN PV */

volatile uint16_t Cell_Voltages_mV[7] = {0};
volatile uint16_t REG18_Raw_ADC = 0;
volatile uint16_t Stack_Voltage_mV = 0;
volatile float Internal_Temp_C = 0.0f;
volatile float Battery_Current = 0;
/* USER CODE END PV */

void SystemClock_Config(void);
static void MX_GPIO_Init(void);
static void MX_SPI1_Init(void);
/**
  * @brief  The application entry point.
  * @retval int
  */
int main(void)
{

  /* MCU Configuration--------------------------------------------------------*/

  /* Reset of all peripherals, Initializes the Flash interface and the Systick. */
  HAL_Init();

  /* Configure the system clock */
  SystemClock_Config();

  /* Initialize all configured peripherals */
  MX_GPIO_Init();
  MX_SPI1_Init();
  /* USER CODE BEGIN 2 */

  // 1. Send the wake-up ping to the BQ76952
  HAL_GPIO_WritePin(GPIOA, GPIO_PIN_4, GPIO_PIN_RESET);
  HAL_Delay(1);
  HAL_GPIO_WritePin(GPIOA, GPIO_PIN_4, GPIO_PIN_SET);
  HAL_Delay(5);


  BQ_Configure_Cell_Count();

  /* USER CODE END 2 */

  /* Infinite loop */
  /* USER CODE BEGIN WHILE */
  while (1) {
    /* USER CODE END WHILE */

    /* USER CODE BEGIN 3 */

	  // Check which hardware fault tripped

	  HAL_GPIO_TogglePin(GPIOA, LED_Pin);

	  BQ_Wake_SPI();// Check that function

	  BQ_Read_All_Cell_Voltages((uint16_t*)Cell_Voltages_mV);

	  REG18_Raw_ADC = BQ_Read_REG18_ADC();

	  Stack_Voltage_mV = BQ_Read_Stack_Voltage();

	  Internal_Temp_C = BQ_Read_Internal_Temp_C();

	  Battery_Current = BQ_Get_Pack_Current_Amps();

	  HAL_Delay(5);

  }
  /* USER CODE END 3 */
}

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


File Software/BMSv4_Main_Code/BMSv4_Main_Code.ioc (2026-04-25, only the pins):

Mcu.UserName=STM32F103C8Tx
PA13.Signal=SYS_JTMS-SWDIO
PA14.Signal=SYS_JTCK-SWCLK
PA3.GPIO_Label=LED
PA3.Signal=GPIO_Output
PA4.GPIO_Label=CS
PA4.Signal=GPIO_Output
PA5.Signal=SPI1_SCK
PA6.Signal=SPI1_MISO
PA7.Signal=SPI1_MOSI

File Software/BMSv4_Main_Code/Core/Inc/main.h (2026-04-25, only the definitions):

#define LED_Pin GPIO_PIN_3
#define LED_GPIO_Port GPIOA
#define CS_Pin GPIO_PIN_4
#define CS_GPIO_Port GPIOA

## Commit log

2026-04-25 Old version are removed
    To keep it simple the manual added version history are deleted. Can be found locally.
    [BMS_Project_One_V1.0.kicad_pcb, BMS_Project_One_V1.0.kicad_sch, BMS_V4.01.kicad_pcb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]
2026-04-25 Name changed
    The name of Ki-Cad file change from V4.013 to V4.
    [BMS_V4.0132.csv, BMS_V4.kicad_pcb, BMS_V4.kicad_sch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]
2026-04-25 Datahseets and Lists are added
    [BMS Entegreleri V25.0.xlsx, BMS_V4.013.xlsx]
2026-04-25 Not important files deleted
    [BMS_V4.0132.csv]
2026-04-25 PACK Pin Connection
    The PACK pin of BQ connected via 10k resistor to BAT+
    [BMS_V4.kicad_pcb, BMS_V4.kicad_sch, bms_ic.kicad_sch]
2026-04-25 Create pr-kicad-diff.yml.txt
    Add Kiri GitHub Action for automated visual diffs
2026-04-25 Trace optimization
    [BMS_V4.kicad_pcb]
2026-04-25 Visual reperesenation setting of ki-cad
2026-04-25 Trace optimization test
    [BMS_V4.kicad_pcb]
2026-04-26 Name standartization
    The file name of stm32code changed and kicad revison is uptadet
    [BMS_V4.kicad_pcb, BMS_V4.kicad_sch, bms_ic.kicad_sch]
2026-04-26 Cell Connections Sub Sheet Added
    Hiarchical sheet have been tried to implement. New section added to kicad schematic.
    [BMS_V4.kicad_sch, CellBalance_Input.kicad_sch, bms_ic.kicad_sch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]
2026-04-26 Small Adjustment
    [BMS_V4.kicad_sch]
2026-04-26 Library for bq76952 is created.
    The library created with basic functions. 7 cells reading logic and bypass shot circuit cell is added.
2026-04-27 Stack Voltage Function Added
2026-05-01 The read and write logic of spi changed
2026-05-01 Current reading functions added
2026-05-02 Rest System changed for bq
    The reset button of bq76965 have changed like stm32
    [CellBalance_Input.kicad_sch, bms_ic.kicad_sch, power.kicad_sch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]
2026-05-02 Reset button corected
    [BMS_V4.kicad_sch, CellBalance_Input.kicad_sch, bms_ic.kicad_sch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]
2026-05-03 Code version 1.0.1-Tested Workes
    Version added, started from v1.0.1 for software
    Went back the previus logic functions fır SPI read and write
2026-05-04 Power Flag Added
    The pcb is updated but there is no change. This is last correction of pcb, after that there will be major change.
    [BMS_V4.kicad_pcb, BMS_V4.kicad_sch, bms_ic.kicad_sch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]
2026-05-04 5V Updated- V4.0.21
    A new IC found and used for 5V. The schematic is done.
    [5V_BomReference.csv, BMS_V4.kicad_sch, CellBalance_Input.kicad_sch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]
2026-05-06 Small change after 5V update
    [can_bus.kicad_sch, power.kicad_sch]
2026-05-07 The Cell Reading Function Corrected /Internal balance are tried
    [BMS_V4.kicad_sch, bms_ic.kicad_sch]
2026-05-13 Extrenal Balance Circuit Added
    [BMS_V4.kicad_sch, CellBalance_Input.kicad_sch, bms_ic.kicad_sch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]
2026-05-16 The safety system add for Contactor
    PhotoMOS system is added but there is not a perfect system for recovery.
    [BMS_V4.csv, BMS_V4.kicad_sch, CellBalance_Input.kicad_sch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]
2026-05-16 Code Updated for 16Cells-Works
    [BMS_V4.kicad_pcb, add_circ_sch.kicad_sch]
2026-05-18 BMS Numbering button added
    [BMS_V4.kicad_sch, add_circ_sch.kicad_sch]
2026-05-19 Temp Read ADDED-STM Connection Done
    [BMS_V4.kicad_pcb, BMS_V4.kicad_sch, CellBalance_Input.kicad_sch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]
2026-05-19 PCB Routing started
    [BMS_V4.kicad_pcb, BMS_V4.kicad_sch, CellBalance_Input.kicad_sch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]
2026-05-19 Balance circuit changed for dublication
    [BMS_V4.kicad_pcb, BMS_V4.kicad_sch, Cell16_In_sch.kicad_sch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]
2026-05-30 Routing begins
    [BMS_V4.kicad_pcb, add_circ_sch.kicad_sch]
2026-06-03 Routing cnt.
    [BMS_V4.kicad_pcb, BMS_V4.kicad_sch, Cell16_In_sch.kicad_sch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]
2026-06-03 Routing Cont.
    [BMS_V4.kicad_pcb]
2026-06-04 Rting Cnt
    [BMS_V4.kicad_pcb]
2026-06-17 Routing Cnt
    [BMS_V4.kicad_pcb, Cell1_In_sch.kicad_sch, bms_ic.kicad_sch]
2026-06-18 Routing and Slick screen adj.
    [BMS_V4.kicad_pcb]
2026-07-05 Fuse added
    [BMS_V4.kicad_pcb, BMS_V4.kicad_sch]
2026-07-12 External MOSFET name correction
    The value of the external balancing MOSFET changed to SI1050X-T1-GE3.
2026-07-12 System Test 1
    [BMS_V4.kicad_pcb]
2026-07-12 Small Adj.
    [BMS_V4.kicad_pcb, Cell16_In_sch.kicad_sch, Cell1_In_sch.kicad_sch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]
2026-07-15 Added some changes
    [BMS_V4.kicad_pcb]
2026-07-15 Last Changes before porduction
    [BMS_V4.kicad_pcb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]
2026-07-19 Gerber File Generated
    [BMS_V4-job.gbrjob]
2026-10-13 Firmware: robust BQ76952 SPI driver, reset recovery, watchdog; README to-do
    - SPI: check echoed address and CRC on every frame, retry on
    0xFFFF00/0xFFFFFF/0xFFFFAA; trigger registers (0x3F, 0x61) are never
    blindly repeated
    - CONFIG_UPDATE: poll Battery Status bit 0 (CFGUPDATE); old code checked
    bit 2 (SLEEP_EN), which is already set by default
    - Subcommand reads wait for completion and verify the 0x60 checksum
    - All RAM settings written in one CONFIG_UPDATE session, then read back
    - POR flag checked every loop; configuration re-applied after a BQ reset
    - RESET() at boot so the S2 button resets the BQ76952 as well
    - IWDG (~2 s, frozen while the debugger halts the core)
    - Safety Status A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
2026-10-13 Balance resistors 10 R -> 22 R (2 W, 2512); README reset-button notes
    - R37, R42 ... R99 (16 parts): HP122WJ0100T4E -> HP122WJ0220T4E in the
    cell-input sheets and the PCB. ~0.8 W each at 4.2 V instead of ~1.7 W.
    Same footprint, BOM-only change for the ordered v4.02 board.
    - README: BQ reset button wiring problem and fix for v4.03, REGIN/REG1
    notes
    Claude-Session: https://claude.ai/code/session_01U1Rdq73FHAWn7HLCu1GGMU
2026-10-13 Add v4.02 BOM with Özdisan data, consistent component values
    - Hardware/BMS_V4/BOM/BMS_V4.02_BOM.xlsx and .csv generated from the
    schematic: one line per part number, Özdisan link, stock and price
    (2026-10-13), quantity to buy for N boards, off-board plugs/jumpers.
    - Schematic and PCB Value fields follow one rule (R: value, C: value +
    voltage, ICs: short part name, connectors: function). Full part number
    moved to hidden MPN / Manufacturer / Supplier / Supplier Link fields.
    - PCB values synced to the schematic (Q1-Q16 showed RQ6E080AJ).
    - R1/R2 marked DNP.
    - README: BOM location, out-of-stock list, naming rule, v4.03 renames.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
2026-10-17 Firmware: selectable cell count, 7S bench-test configuration
    - BMS_CELL_CONFIG in bq76952.h picks 7, 13 or 16 cells; sets NUM_CELLS
    and BQ_VCELL_MODE (7S = 0x803F: cells 1-6 on VC1-VC6, top cell on VC16).
    - Compile-time checks: NUM_CELLS matches the VCell Mode bits, top cell on VC16.
    - Balance status adds cell_balance_mask in pack order (hw mask is per VC input).
    - README: 7S wiring note.
    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
2026-10-17 7S: match bench wiring, wiring check, CC Gain from shunt value
    - 7S default is now cells 1-7 on VC1-VC7 (VCell Mode 0x007F), the wiring
    on the bench. BMS_7S_TOP_ON_VC16 selects the other wiring (0x803F).
    With 0x803F and this wiring, cell 16 read 0 V and blocked balancing.
    - BQ_Input_mV[16] shows all inputs; Stack_Diff_mV = stack - sum of cells.
    - CC Gain (0x91A8) and Capacity Gain written from BQ_SHUNT_MOHM, so the
    current register is real mA (+/-32.7 A instead of +/-16.4 A).
    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
2026-10-18 bom correction
2026-10-21 Bom list updated
2026-10-21 BOM Update

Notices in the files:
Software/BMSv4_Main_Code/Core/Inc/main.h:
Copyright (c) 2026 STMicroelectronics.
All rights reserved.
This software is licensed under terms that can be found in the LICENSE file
